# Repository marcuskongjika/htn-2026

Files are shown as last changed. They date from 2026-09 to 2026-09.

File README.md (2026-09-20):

<div align="center">

# ♻️🔋 SortiFy

### Catching hidden batteries *before* they reach the recycling truck.

**SortiFy scans waste for hidden batteries using sensors; it flags and reroutes them before they can cause harm — protecting recycling facilities and waste bins from the hazards posed by lithium batteries.**










</div>

---

## The problem

Vapes, earbuds, toys, greeting cards that sing — more and more of what we throw away has a **lithium-ion battery sealed inside it**. When those cells get crushed in a garbage truck or a sorting line they ignite, and the result is thousands of reported fires at recycling and waste facilities every year.

The catch is that these items **look like ordinary plastic**. A person glancing at a bin can't tell. Neither can a camera. By the time anyone finds out, the item is already in the compactor.

Most solutions work downstream, at the facility. **SortiFy works at the source — the moment you throw something away.**

## What it does

Drop an item on the platform. In a few seconds SortiFy:

1. **notices it** — a load cell feels the weight land,
2. **looks at it** — a camera frame goes to Google's Gemini, which says what the item appears to be made of,
3. **looks *inside* it** — an inductive sensor under the platform checks for metal that no camera could see,
4. **decides** — and the platform physically tilts the item into one of two bins:

| | Bin | What lands here |
|---|---|---|
| 🔋 | **Battery side** | Anything with metal detected in it — routed to e-waste |
| ♻️ | **Non-battery side** | No metal detected — safe for the normal stream |

Then it levels out and is ready for the next item roughly a second later.

### The idea in one sentence

> **A camera sees the outside. An inductive sensor sees the inside. The interesting moment is when they disagree.**

When Gemini says *"that's plastic"* and the sensor says *"there's metal in there"*, you are very probably holding a vape, a toy or a pair of earbuds — and SortiFy says so:

```
sensed: metal_present=True plastic=True -> side=battery
        [looks like plastic but metal detected inside - possible hidden battery]
```

## How it works

```mermaid
flowchart LR
    subgraph sense["Sense"]
        LC["Load cell + HX711<br/><i>item placed?</i>"]
        CAM["Camera"]
        IND["Inductive sensor<br/><i>metal inside?</i>"]
    end
    subgraph think["Decide — Raspberry Pi 5"]
        GEM["Gemini vision<br/><i>looks like plastic?</i>"]
        RULE{"Decision rule"}
        LOG["Explanation<br/>+ logs"]
    end
    subgraph act["Act"]
        SERVO["2 × ST3215 smart servos"]
        BED["Tilting platform"]
    end

    LC -- "weight jumps > 10 g" --> CAM
    CAM --> GEM
    GEM -. "context only" .-> LOG
    IND == "decides the side" ==> RULE
    IND --> LOG
    RULE --> SERVO --> BED
    BED --> B1["🔋 battery bin"]
    BED --> B2["♻️ non-battery bin"]
```

The whole thing is one explicit state machine ([`sorter/main.py`](sorter/main.py)):

```mermaid
stateDiagram-v2
    direction LR
    [*] --> WAITING
    WAITING --> SENSING: weight rises > 10 g
    SENSING --> ACTUATING: metal read + frame classified
    ACTUATING --> HOLDING: platform tilted
    HOLDING --> RESETTING: item has slid off
    RESETTING --> WAITING: level again (~1 s)
    SENSING --> RESETTING: any error → back to level
```

### The decision rule — and why the AI doesn't get the final say

```python
def sort_side(plastic: bool, metal_present: bool) -> str:
    return BATTERY_SIDE if metal_present else NON_BATTERY_SIDE
```

That's the entire rule, and it is short on purpose.

- **The inductive sensor alone decides where an item goes.** Metal detected → battery side. No two ways about it.
- **Gemini never moves an item.** A camera can't see inside anything, so vision is never allowed to put an item on the battery side by itself — and it can never talk an item with metal in it *out* of the battery side. Nothing in the code "assumes" a battery.
- **What Gemini adds is meaning.** Metal + *looks like plastic* is the case this machine exists to catch, and that is the explanation it logs. Metal + *looks like a can* is just a can.
- **If the API is slow, down, or returns junk** (we hit real `503 model overloaded` errors during the hackathon), the classifier returns a result that claims nothing and the item is *still sorted correctly* — the sensor reading was all the rule needed.

A generative model is what made recognising arbitrary household waste possible in a weekend: no dataset, no training, just a prompt and an enforced JSON schema. Keeping it out of the safety-critical path is what makes the machine trustworthy.

## Hardware

| Part | Job | Notes |
|---|---|---|
| **Raspberry Pi 5** (Ubuntu 24.04) | Runs everything | One Python process |
| **Camera** | Frame for Gemini | OpenCV capture |
| **LJ18A3-8-Z/BX inductive sensor** | Metal yes / no | NPN, open collector, active-low on GPIO17 |
| **Bar load cell + HX711** | "An item was placed" | Bit-banged over two GPIOs |
| **2 × Feetech ST3215 smart servos** | Tilt the platform | 12 V, 30 kg·cm, 12-bit absolute encoders, serial bus |
| **3D-printed frame, platform, legs, camera mount** | The machine itself | Designed in Autodesk Inventor — STEP files in this repo |

### Wiring (Raspberry Pi 5 header)

| Pi pin | GPIO | Connects to |
|---|---|---|
| 8 | GPIO14 (TX) | Servo data line, **through a 1 kΩ resistor** |
| 10 | GPIO15 (RX) | Servo data line, directly |
| 11 | GPIO17 | Inductive sensor signal (black wire) |
| 29 | GPIO5 | HX711 `DT` |
| 31 | GPIO6 | HX711 `SCK` |
| 17 | 3.3 V | HX711 `VCC` |
| 6, 9, 25 | GND | Common ground — servos, supply −, both sensors |

The servos run from their own 12 V supply. **Battery/supply positive never touches the Pi.**

## The engineering, honestly

The Devpost says *"physical faults lacked error logs."* Here is what that looked like in the small hours, and what we built because of it.

**We threw away the servo controller board and talked to the servos directly.**
Our USB bus-servo adapter never produced a single reply — not from a laptop, not from the Pi, not with a known-good servo. So we removed it. The ST3215 speaks half-duplex serial at 1 Mbps on one wire; [`sts_bus.py`](sorter/actuators/sts_bus.py) implements that protocol from scratch over the Pi's own UART, with TX and RX tied to the data line through a single resistor. The servos answered on the first try.

**The echo trap.** On a one-wire bus you hear everything you say. Vendor SDKs mistake that echo for the servo's reply — so they cheerfully "find" a servo at every ID, including with nothing plugged in. Our driver reads back and verifies its own echo, which turns a nuisance into a free wiring self-test with three *different* errors instead of one useless timeout:

| Error | What it means |
|---|---|
| `BusWiringError` | We spoke and heard nothing — RX isn't on the wire |
| `BusContentionError` | We heard something we didn't say — a short, or a second driver |
| `ServoTimeout` | Echo perfect, servo silent — it's the servo's power, cable or ID |

**Two servos, one mechanism, facing opposite ways.** [`ServoPair`](sorter/actuators/servo_pair.py) sends both goals in a single sync-write packet so they start in the same instant. Calibration is done by hand, not by maths: torque off, move the platform to level and to each end, and [`read_positions.py`](sorter/tests/read_positions.py) records each servo's own encoder value — detecting by itself which servo is mirrored. No kinematics, no invert flags.

**Three layers between a bug and a broken platform.** Travel limits are written into each servo's EEPROM, so the *servo* refuses to go past them whatever the code asks for. Setpoints sit a further margin inside those limits, so overshoot never reaches them. And torque is capped in config.

**An HX711 that doesn't lie.** That chip treats a clock pulse longer than 60 µs as "power down" — and Python on Linux can be pre-empted mid-pulse. [`hx711.py`](sorter/sensors/hx711.py) drives the pins through `lgpio` directly (~4 µs a pulse), times every pulse, and throws away any reading that was disturbed instead of trusting it. A dead data line is reported as `HX711StuckLow` rather than as a very confident zero grams.

**Weight as a *change*, not a number.** The scan starts when the weight *rises* more than 10 g above a resting level that is re-measured after every dump and follows slow drift. The scale's zero never has to be right — which matters when a load cell gets swapped halfway through a hackathon.

**It all runs without the hardware.** Every device sits behind a mock, and the hardware logic is tested against simulated servos, a simulated HX711 and gpiozero's mock pins — **165 tests**, runnable on a laptop. That is how a team writes code against a single rig.

## Run it

```bash
git clone https://github.com/marcuskongjika/htn-2026.git
cd htn-2026/sorter
python3 -m venv .venv && source .venv/bin/activate
pip install -r requirements.txt
cp .env.example .env          # add GEMINI_API_KEY; MOCK_HARDWARE=1 on a laptop, 0 on the Pi
```

| Command | What it does |
|---|---|
| `python main.py` | The full sorter. A weight landing on the platform starts each scan |
| `python main_enter.py` | Same pipeline, but **Enter** starts each scan — no load cell needed |
| `python -m pytest tests -q` | 165 tests, no hardware required |
| `MOCK_HARDWARE=1 python main.py --cycles 1` | One full cycle on a laptop, nothing attached |

### Bring-up and diagnostic tools

Every one of these exists because something broke. The ones that move hardware ask first.

| Tool | Use it when |
|---|---|
| `python -m actuators.sts_bus scan` | "Are the servos alive?" — IDs, position, voltage, temperature, limits |
| `python -m actuators.sts_bus loopback` | Prove the UART and the TX/RX tie before a servo is even connected |
| `python tests/read_positions.py` | Calibrate: move the platform by hand, record level / min / max, save |
| `python -m actuators.calibration apply` | Write the travel limits into the servos' EEPROM |
| `python tests/goto_setpoints.py` | Drive the platform to level / battery / non_battery and nothing else |
| `python tests/sensor_tilt_loop.py` | Metal sensor → platform, without the camera or the API |
| `python tests/load_cell_read.py` | Live scale readout; tare, calibrate against a known weight, save |
| `python tests/gpio_check.py` | "Is it the Pi pin, the jumper wire, or the board?" — answers exactly that |

Full setup, wiring and bring-up order: **[`sorter/README.md`](sorter/README.md)**.

## Repository

```
htn-2026/
├── sortify_*.stp                 CAD — platform, base, legs, floor, camera mount (STEP)
└── sorter/
    ├── main.py                   state machine, load-cell triggered
    ├── main_enter.py             same pipeline, Enter triggered
    ├── config.py                 every pin, threshold, margin and timing in one place
    ├── logic/decision.py         the sorting rule (it's one line)
    ├── vision/                   camera capture + Gemini classifier
    ├── sensors/                  hx711 driver, load cell, inductive metal sensor
    ├── actuators/
    │   ├── sts_bus.py            ST3215 protocol over the Pi's UART, from scratch
    │   ├── servo_pair.py         two servos as one mechanism
    │   └── calibration.py        measured zero / travel / mirroring, shared everywhere
    ├── tests/                    165 tests + the physical bring-up tools
    └── *_calibration.json        what we measured on the rig
```

## What we learned

- **Details decide whether a system works.** A pin one position over, a resistor on the wrong leg, a jumper that *looks* seated.
- **Test components early and alone.** Every part that was proven by itself before integration cost us minutes. Every part that wasn't cost us hours.
- **Hardware and software fail differently.** Software tells you what went wrong. Hardware just stops — so we made the software say *which side of the wire* to look at.
- **Calibrate against real objects, not assumptions.** The servos' limits, the scale's counts-per-gram, the sensor's range: every number in this repo that matters was measured on the rig.

## What's next

- **More categories** — plastics, metals, glass, paper, each to its own stream
- **Broader sensing** — more item types, more robust detection of pouch cells
- **Bigger installations** — campuses, airports, offices
- **Contamination insights** — give facilities data on what is actually being thrown away, and where

## Team

Built over one weekend at **Hack the North 2026** by

**[Sharisse Ji](https://www.linkedin.com/in/sharisseji/)** · **[Zhi Wei Zhang](https://www.linkedin.com/in/zhiweizhang27)** · **[Andrii Bessarab](https://www.linkedin.com/in/andriibessarab/)** · **[Marcus Kongjika](https://www.linkedin.com/in/marcus-kongjika-b5476b2b8/)**

<div align="center">

**[▶ See SortiFy on Devpost](https://devpost.com/software/sortify-fbow2t)**

*Built with Python, Google Gemini and Autodesk Inventor.*

</div>

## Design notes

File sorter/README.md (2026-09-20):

# Battery Sorter

Raspberry Pi 5 pipeline that flags waste items likely to contain a hidden
battery. A load cell (HX711) and an inductive metal sensor cross-check a

Gemini photo classification of the item (whether it is plastic, and whether it
likely contains a hidden battery), then drive two STS3215 smart servos to tilt
the item to the **battery side** or the **non-battery side**. The induction sensor
alone decides: metal detected -> battery side, no metal -> non-battery side. The
camera explains the result (plastic + metal = a possible hidden battery); it never
moves an item.

The pipeline is an explicit state machine (`main.py`) gated by the load cell —
nothing is captured until an item's weight is sensed:

```
WAITING -> (weight >= WEIGHT_TRIGGER_G) -> SENSING -> ACTUATING -> HOLDING -> RESETTING -> WAITING
   '-------------------- (below trigger: keep polling) --------------------'
```

WAITING polls the load cell. When an item's weight crosses `WEIGHT_TRIGGER_G`,
SENSING lets it settle, reads the metal sensor, and classifies the camera frame;
the bed then tilts (metal detected -> battery side; no metal -> non-battery side), holds
for `TILT_HOLD_S` (default 5 s), returns to level, and waits for the next item.
On real hardware the load cell tares at start-up and after each dump.

Every hardware-touching module (`sensors/`, `vision/camera.py`,
`actuators/`) has a **mock mode** that returns synthetic data instead of
touching real GPIO/serial/camera. This is not a fallback bolted on — it's
how the whole pipeline is meant to be developed and demoed before hardware
is available.

## Install

```bash
cd sorter
python3 -m venv .venv
source .venv/bin/activate
pip install -r requirements.txt
```

`RPi.GPIO` only installs on ARM (the Pi itself); on a laptop, `pip install`
will skip it via the platform marker in `requirements.txt`, and mock mode
never imports it anyway.

## Configure

```bash
cp .env.example .env
```

Edit `.env` and set:

```
GEMINI_API_KEY=your-real-key-here
MOCK_HARDWARE=1   # 1 on a laptop with no hardware, 0 on the Pi with hardware attached
```

`.env` is gitignored — never commit real keys.

## Run in mock mode (no hardware attached)

With `MOCK_HARDWARE=1` (the default), the whole pipeline — including a
canned Gemini-shaped response, no network call — runs end to end on a
laptop. The mock load cell's baseline weight sits above `WEIGHT_TRIGGER_G`, so
it fires every loop; it runs until Ctrl+C:

```bash
python main.py                                # runs until Ctrl+C
TILT_HOLD_S=1 python main.py --cycles 2       # bounded demo: 2 cycles, short hold
```

`--cycles N` stops after N completed cycles; `TILT_HOLD_S` tunes the hold at the
tilt. Every state transition and sensor/decision value is logged to stdout and
to `logs/sorter.log` (rotating, see `config.LOG_MAX_BYTES` /
`config.LOG_BACKUP_COUNT`).

To test just the material classifier against the real Gemini API while
everything else stays mocked, set `MOCK_HARDWARE=0` but note that will also
try to open the camera/GPIO/serial — see the bring-up order below for how
to exercise modules individually instead.

Run the decision-logic unit tests any time (pure function, no mocking
needed):

```bash
python -m pytest tests/test_decision.py -v
```

## Testing

All of these run without hardware. Activate the venv first (`source .venv/bin/activate`).

**Mock Gemini + decision unit tests** (offline, no API key, no camera):

```bash
python -m pytest tests/test_classifier.py tests/test_decision.py -v
```

`test_classifier.py` mocks Gemini two ways: the built-in canned-response path,
and a *fake `google.genai` SDK* injected into `sys.modules` so the real
request-build / JSON-parse code in `classify_material` runs offline. It also
covers fail-toward-"flagged" behavior on malformed output, errors, and timeouts.

**Webcam smoke test** (real camera capture + *mocked* Gemini) — captures one
frame from this machine's webcam, verifies the JPEG, then classifies it in mock
mode so no API quota is spent:

```bash
python -m tests.webcam_smoke              # camera index 0 (default webcam)
python -m tests.webcam_smoke --index 1    # a different camera
python -m tests.webcam_smoke --real-gemini  # real camera + REAL Gemini (needs GEMINI_API_KEY)
```

> **WSL2 note:** OpenCV inside WSL2 cannot see the Windows webcam — there is no
> `/dev/video*` unless you attach the USB device with `usbipd-win` and run a
> UVC-capable WSL kernel. The simplest path on Windows+WSL is to run the webcam
> test under **Windows Python** instead:
>
> ```powershell
> cd <repo>\sorter
> python -m venv .venv-win
> .venv-win\Scripts\activate
> pip install opencv-python python-dotenv google-genai
> python -m tests.webcam_smoke --real-gemini
> ```

**Seeing how Gemini categorizes an item** — `--real-gemini` above prints the raw
JSON verdict (`plastic`, `plastic_confidence`, `likely_contains_battery`,
`confidence`). `plastic` is `true` when `plastic_confidence` exceeds 0.5
(`config.PLASTIC_CONFIDENCE_THRESHOLD`). You can also
run the classifier standalone against the real API (`MOCK_HARDWARE=0`, key set):

```bash
python -m vision.classifier   # captures a frame and prints the classification
```

Both `vision/classifier.py` and `main.py` also log `Gemini classification: {...}`
/ `classified: {...}` at INFO to stdout and `logs/sorter.log`.

## Hardware bring-up order (on the real Pi)

Bring the system up incrementally, in this order, rather than plugging
everything in and running `main.py` cold:

1. **Verify power rails before connecting the Pi.** Confirm 3.3V and GND on
   the load cell and metal sensor headers with a multimeter before
   attaching anything to the Pi's GPIO pins.
2. **Bring up the Pi standalone — camera capture + one real Gemini call.**
   With `MOCK_HARDWARE=0` and a real `GEMINI_API_KEY` set:
   ```bash
   python -m vision.camera      # writes capture_test.jpg
   python -m vision.classifier  # captures a frame and classifies it
   ```
3. **`python -m sensors.load_cell` alone, calibrate zero/scale.** Run it
   standalone, tare with nothing on the scale, then place a known reference
   weight and adjust `HX711_REFERENCE_UNIT` / `HX711_ZERO_OFFSET` in
   `config.py` until `read_weight_g()` matches reality.
4. **`python -m sensors.metal_sensor` alone, confirm it toggles near
   metal.** Wave a metal object near the sensor face and confirm
   `metal_present` flips (LOW = detected, per the sensor's active-low
   wiring).
5. **Bring up the servo bus — see "Servo bring-up" below.** Loopback first
   (no servo attached), then scan, then a single move with the horn free,
   and only then `python -m actuators.servo_controller`.
6. **Run `logic/decision.py`'s `sort_side()` against printed sensor/vision
   output with servos disconnected.** Feed real metal + plastic readings from
   steps 2-4 into `sort_side(plastic, metal_present)` by hand (or via
   `python -m tests.test_decision`) and sanity-check which bin each combination
   picks before anything can physically move.
7. **Run `main.py` fully on the shared battery rail with a real test
   item.** Only after 1-6 pass, set `MOCK_HARDWARE=0` and run
   `python main.py` with power to the full system and a real item.

## Servo bring-up (direct UART, no adapter board)

The STS3215 talks half-duplex serial at 1 Mbps on a single data wire.
`actuators/sts_bus.py` speaks that protocol over the Pi's own UART and does
the job the USB adapter board used to do (framing, discarding its own echo,
parsing replies). No vendor SDK is involved.

### One-time Pi setup

On a Pi 5 the header UART (GPIO14/15) is off by default. Add to
`/boot/firmware/config.txt` and reboot:

```
dtparam=uart0=on
```

It appears as `/dev/ttyAMA0` (the default `SERVO_PORT`). Check with
`pinctrl get 14,15` - the pins should show `TXD0` / `RXD0`. If
`/boot/firmware/cmdline.txt` contains `console=ttyAMA0` or a
`serial-getty@ttyAMA0` service is running, remove/disable it so nothing else
writes to the servo bus. The user must be in the `dialout` group.

### Wiring

```
Pi GPIO14 (TX, pin 8)  --[ 1 kOhm ]--+
Pi GPIO15 (RX, pin 10) --------------+---- servo DATA
Pi GND (pin 6) --------------------------- servo GND  and  battery -
battery + -------------------------------- servo V+        (NEVER to the Pi)
```

The resistor is what makes one wire work both ways: the Pi drives the line
through it, and the servo can still pull the line when it replies. TX idling
high through the resistor is also the line's pull-up.

**Before connecting RX:** power the servo on its own and measure DATA to GND
with a multimeter. It must be 3.6 V or less. If it is near 5 V, put a voltage
divider or level shifter in front of GPIO15 - the Pi's pins are 3.3 V.

### Bring-up order

```bash
python -m actuators.sts_bus loopback      # 1. NO servo attached. Proves the UART runs at 1 Mbps and RX sees TX
python -m actuators.sts_bus scan --all    # 2. servo attached + powered: lists every ID that answers
python -m actuators.sts_bus watch 1       # 3. torque off; turn the horn by hand and read the ticks (pose recording)
python -m tools.nudge 1                   # 4. first motion: +100 ticks slowly at 30% torque, then back. Asks before moving;
                                          #    refuses if the servo's stored angle limits would turn it into a big swing
python -m actuators.sts_bus move 1 2048   #    then a full move to centre, horn free
python -m actuators.servo_controller      # 5. home -> safe -> flagged -> home (MOCK_HARDWARE=0)
```

The bus reports *which side* is broken instead of a generic timeout:

| Error | Meaning | Look at |
|---|---|---|
| `BusWiringError` | We sent bytes and heard nothing, not even our own echo | TX/RX tie, UART enabled, right `/dev/tty*` |
| `BusContentionError` | What we heard while sending wasn't what we sent | Short, second device on the line, bad ground |
| `ServoTimeout` | Echo was perfect, the servo said nothing | Servo power, the 3-pin cable, servo ID, baud rate |

Servo IDs come from `.env` (`SERVO_ID_SAFE_GATE`, `SERVO_ID_FLAGGED_GATE`).
Setting both to the same ID is the single-servo build: one servo tilts either
way from home. A USB bus adapter still works - set `SERVO_PORT=/dev/ttyACM0`;
the echo is auto-detected either way.

## Sorting rule

`logic/decision.py`, `sort_side(plastic, metal_present)`. **The induction sensor is the only
thing that decides the side:**

- **metal detected -> the battery side.** No two ways about it: whatever the camera thinks,
  an item with metal in it never goes to the non-battery side.
- **no metal -> the non-battery side.** That includes things that aren't plastic (paper,
  glass, food): "not plastic" is not evidence of a battery, and nothing is assumed.

Gemini's answer (`plastic`, and its `likely_contains_battery` guess) is **logged, never acted
on** - a camera can't see inside anything. What it adds is the explanation, from
`describe()`: *plastic + metal* is the case this machine exists to catch, "looks like plastic
but metal detected inside - possible hidden battery". If the Gemini call fails or times out,
the classifier returns a result that claims nothing (`plastic: False,
likely_contains_battery: False`) and the item is still sorted correctly, because the sensor
reading is all that was needed.

The code only ever says `battery` / `non_battery`. Which physical end of the bed each one is
lives in one place: `BATTERY_SIDE_SETPOINT` in `config.py` (or `.env`) - `max` by default,
so `non_battery` is `min`. Swap the bins on the table, change that one value. The bed rests
at `go_level()` between items. In `main.py` the load cell gates the pipeline (an item is only
scanned once its weight is sensed); `main_enter.py` is the same pipeline started by pressing
Enter, with no load cell involved.

## Directory structure

```
sorter/
├── config.py                    # pins, calibration constants, thresholds, .env loading
├── sensors/
│   ├── load_cell.py              # HX711 wrapper
│   └── metal_sensor.py           # inductive sensor wrapper
├── vision/
│   ├── camera.py                 # OpenCV frame capture
│   └── classifier.py             # Gemini plastic + battery classification
├── actuators/
│   ├── sts_bus.py                # STS servo protocol over the Pi UART (half-duplex) + bring-up CLI
│   ├── servo_pair.py             # leader/follower bed pair: go_level / go_min / go_max (used by main.py)
│   └── servo_controller.py       # legacy home / move_safe / move_flagged demo (not used by main.py)
├── logic/
│   └── decision.py               # pure sort_side(plastic, metal) rule
├── tests/
│   ├── test_decision.py          # unit tests for the sorting rule
│   ├── test_sts_bus.py           # servo bus tests against a fake wire + fake servo
│   └── test_nudge.py             # nudge tool against a simulated moving servo
├── tools/
│   └── nudge.py                  # first-motion test: small, slow, gentle move and back
├── main.py                       # the state machine loop
├── .env.example
├── requirements.txt
└── README.md
```

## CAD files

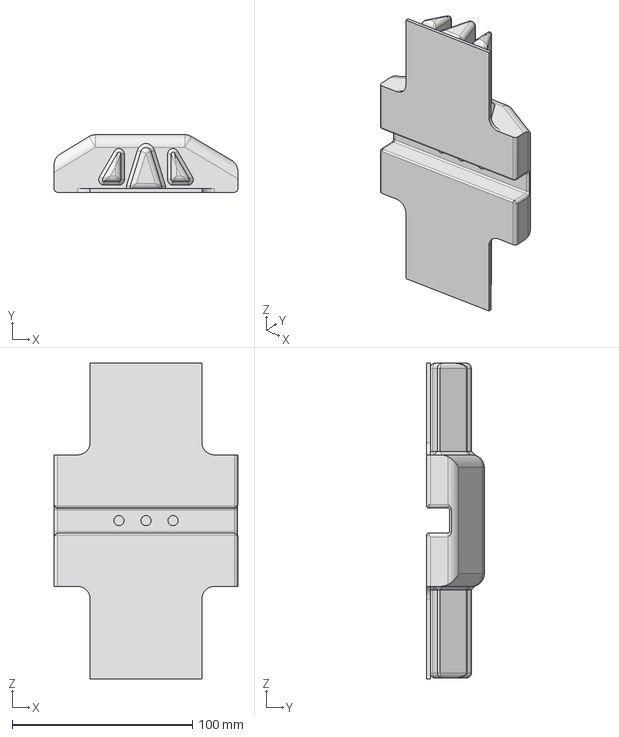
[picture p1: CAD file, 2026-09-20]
sortify_base_cantilever.stp
102.0 x 32.0 x 175.4 mm

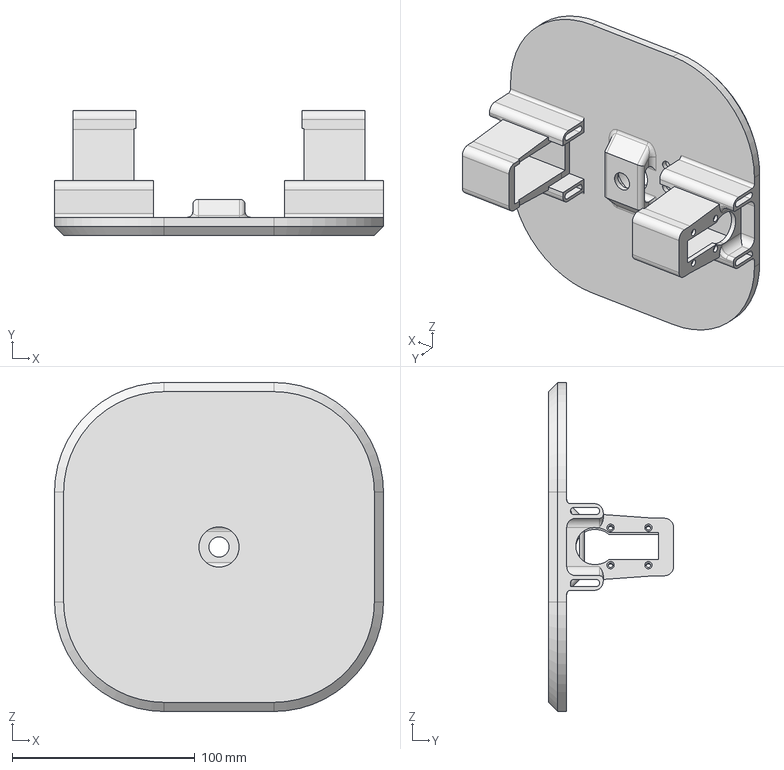
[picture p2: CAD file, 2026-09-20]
sortify_platform.stp
180.0 x 68.5 x 180.0 mm

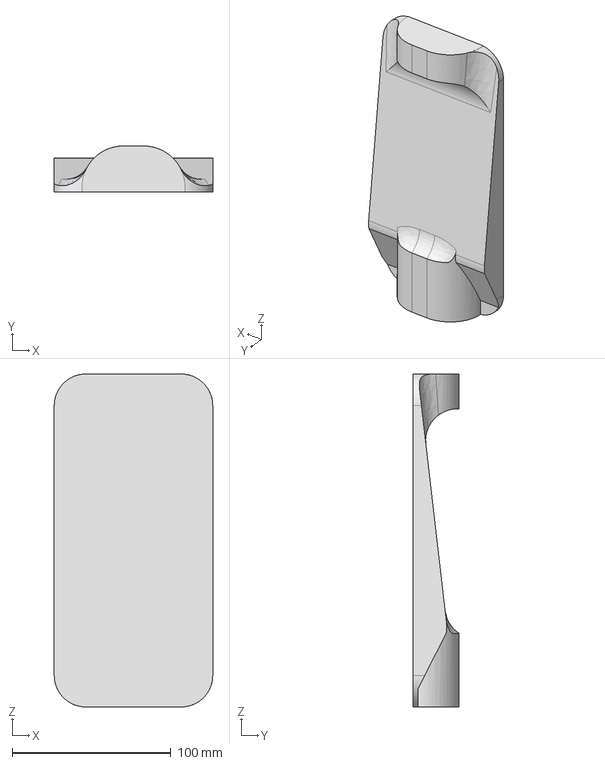
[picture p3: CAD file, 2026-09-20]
sortify_floor.stp
100.0 x 29.0 x 210.0 mm

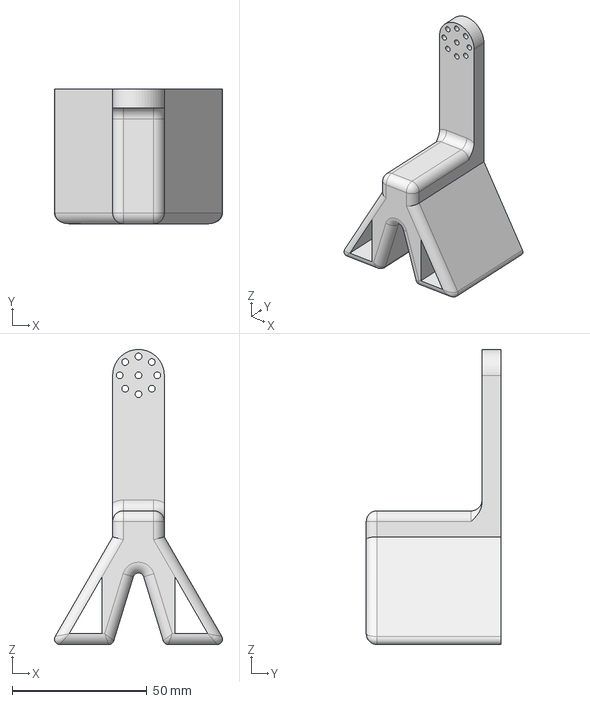
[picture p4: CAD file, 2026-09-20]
sortify_leg.stp
62.5 x 50.0 x 109.6 mm

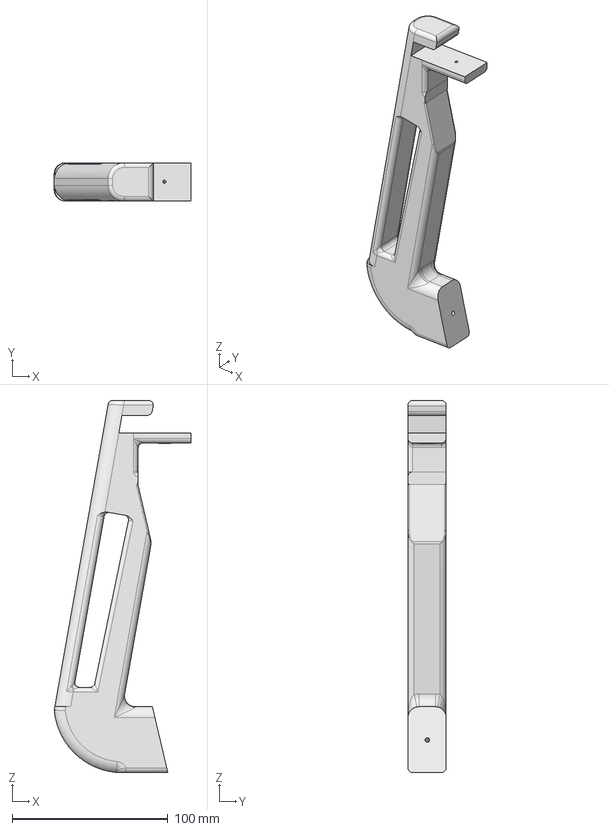
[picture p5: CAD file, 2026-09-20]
sortify_camera_mount.stp
87.7 x 24.6 x 238.8 mm

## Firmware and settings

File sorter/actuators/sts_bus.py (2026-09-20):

"""Feetech STS/ST-series servo bus, spoken directly over a serial port.

This replaces the USB bus servo adapter board *and* the vendor SDK. The Pi's
own UART (GPIO14 TX / GPIO15 RX, `/dev/ttyAMA0` on a Pi 5) is wired straight
to the servo's one-wire data line:

    Pi GPIO14 (TX, pin 8)  --[ 1k ]--+
    Pi GPIO15 (RX, pin 10) ----------+---- servo DATA
    Pi GND ------------------------------- servo GND + battery -
    battery + ---------------------------- servo V+   (never to the Pi)

Because TX and RX share that one wire, every byte we send arrives back on RX
before the servo's reply does. This module is the "translation" the adapter
board used to do: it frames packets, swallows its own echo, and parses the
reply. The echo is also a free wiring self-test, which is why there are three
distinct failures instead of one generic timeout:

    BusWiringError      we sent bytes and heard nothing  -> RX isn't on the wire
    BusContentionError  we heard something else          -> the line is being fought over
    ServoTimeout        echo was perfect, servo was silent -> servo side (power, cable, ID, baud)

Packet format, both directions (low byte first for 16-bit values):

    FF FF | ID | LEN | INSTRUCTION or ERROR | PARAMS... | CHECKSUM
    LEN = len(PARAMS) + 2          CHECKSUM = ~(ID + LEN + INSTR + PARAMS) & 0xFF

Bring-up CLI (run from sorter/):

    python -m actuators.sts_bus loopback        # no servo needed: proves UART + TX/RX tie at full baud
    python -m actuators.sts_bus scan [--all]    # who is on the bus, and what do they report
    python -m actuators.sts_bus watch <id>      # torque off, live position - for recording poses
    python -m actuators.sts_bus move <id> <pos> # one move at config speed/acc
"""
from __future__ import annotations

import logging
import os
import sys
import time

log = logging.getLogger(__name__)

# --- Protocol constants ------------------------------------------------------
HEADER = b"\xff\xff"
BROADCAST_ID = 0xFE

INST_PING = 0x01
INST_READ = 0x02
INST_WRITE = 0x03
INST_SYNC_WRITE = 0x83

# Register addresses (STS3215 control table)
ADDR_ID = 5
ADDR_MIN_ANGLE_LIMIT = 9      # 2 bytes, EEPROM
ADDR_MAX_ANGLE_LIMIT = 11     # 2 bytes, EEPROM
ADDR_MODE = 33                # 0 = position servo
ADDR_TORQUE_ENABLE = 40
ADDR_ACC = 41                 # start of the 7-byte block write_pos_ex writes
ADDR_GOAL_POSITION = 42
ADDR_GOAL_SPEED = 46          # 2 bytes; in wheel mode this IS the command (bit 15 = reverse)
ADDR_TORQUE_LIMIT = 48        # 2 bytes, 0-1000
ADDR_LOCK = 55                # 0 = EEPROM writable, 1 = locked
ADDR_PRESENT_POSITION = 56    # start of the 15-byte feedback block

MODE_POSITION = 0             # go to an angle and hold it
MODE_WHEEL = 1                # spin continuously at a speed, like a motor

FEEDBACK_LEN = 15
POSITION_MAX = 4095
TICKS_PER_REV = 4096

# Status-packet error bits
ERROR_BITS = {0: "voltage", 1: "sensor", 2: "temperature", 3: "current", 5: "overload"}


class StsBusError(RuntimeError):
    """Base class for everything this module raises."""


class BusWiringError(StsBusError):
    """We transmitted and heard nothing back, not even our own echo."""


class BusContentionError(StsBusError):
    """What came back while we were transmitting wasn't what we sent."""


class ServoTimeout(StsBusError):
    """The bus is fine (echo intact) but the servo didn't answer."""

    def __init__(self, servo_id: int) -> None:
        super().__init__(f"servo {servo_id} did not reply (bus echo was fine - check servo power, cable, ID, baud)")
        self.servo_id = servo_id


class BadReply(StsBusError):
    """A reply arrived but failed validation (checksum, ID, or length)."""


def build_packet(servo_id: int, instruction: int, params: bytes = b"") -> bytes:
    body = bytes([servo_id, len(params) + 2, instruction]) + bytes(params)
    return HEADER + body + bytes([~sum(body) & 0xFF])


def _signed(value: int, sign_bit: int) -> int:
    """STS servos use sign-magnitude: one bit is the minus sign, the rest is the number."""
    magnitude = value & ((1 << sign_bit) - 1)
    return -magnitude if value & (1 << sign_bit) else magnitude


class StsBus:
    def __init__(
        self,
        port: str,
        baudrate: int = 1_000_000,
        reply_timeout_s: float = 0.05,
        echo: bool | None = None,
        serial_port=None,
    ) -> None:
        """Open the bus.

        echo: True = TX and RX share the wire (direct UART wiring); False = an
        adapter that hides the echo; None = find out by probing once.
        serial_port: an already-open pyserial-like object (used by the tests).
        """
        self.port = port
        self.reply_timeout_s = reply_timeout_s
        if serial_port is not None:
            self._ser = serial_port
        else:
            import serial  # imported here so mock mode / tests never need pyserial

            self._ser = serial.Serial(port, baudrate, timeout=0.005)
        self.echo = self._detect_echo() if echo is None else echo
        log.info("StsBus open on %s @ %d baud (echo=%s)", port, baudrate, self.echo)

    # --- low level -----------------------------------------------------------
    def _read_exact(self, count: int, timeout_s: float) -> bytes:
        got = bytearray()
        deadline = time.monotonic() + timeout_s
        while len(got) < count and time.monotonic() < deadline:
            got += self._ser.read(count - len(got))
        return bytes(got)

    def _detect_echo(self) -> bool:
        probe = build_packet(BROADCAST_ID, INST_PING)  # harmless: moves nothing
        self._ser.reset_input_buffer()
        self._ser.write(probe)
        self._ser.flush()
        heard = self._read_exact(len(probe), 0.05)
        time.sleep(0.01)  # let any servo's answer to the probe arrive, then drop it
        self._ser.reset_input_buffer()
        return heard == probe

    def _send(self, packet: bytes) -> None:
        self._ser.reset_input_buffer()
        self._ser.write(packet)
        self._ser.flush()
        if not self.echo:
            return
        heard = self._read_exact(len(packet), 0.05)
        if not heard:
            raise BusWiringError(
                f"sent {len(packet)} bytes on {self.port} and heard nothing - RX is not seeing TX "
                "(check the TX/RX tie, and that the UART is enabled)"
            )
        if heard != packet:
            raise BusContentionError(
                f"sent {packet.hex(' ')} but heard {heard.hex(' ')} - something else is driving the data line"
            )

    def _read_reply(self, servo_id: int, timeout_s: float) -> tuple[int, bytes]:
        """Returns (error_byte, params). Raises ServoTimeout / BadReply."""
        head = self._read_exact(4, timeout_s)  # FF FF ID LEN
        if len(head) < 4:
            raise ServoTimeout(servo_id)
        if head[:2] != HEADER:
            raise BadReply(f"servo {servo_id}: reply did not start with FF FF: {head.hex(' ')}")
        reply_id, length = head[2], head[3]
        rest = self._read_exact(length, timeout_s)  # ERROR PARAMS... CHECKSUM
        if len(rest) < length:
            raise BadReply(f"servo {servo_id}: reply cut short: {(head + rest).hex(' ')}")
        if ~(reply_id + length + sum(rest[:-1])) & 0xFF != rest[-1]:
            raise BadReply(f"servo {servo_id}: bad checksum: {(head + rest).hex(' ')}")
        if reply_id != servo_id:
            raise BadReply(f"asked servo {servo_id} but servo {reply_id} answered")
        return rest[0], rest[1:-1]

    def _transact(self, servo_id: int, instruction: int, params: bytes = b"", timeout_s: float | None = None):
        self._send(build_packet(servo_id, instruction, params))
        if servo_id == BROADCAST_ID:
            return 0, b""  # nobody answers a broadcast write
        return self._read_reply(servo_id, self.reply_timeout_s if timeout_s is None else timeout_s)

    # --- public API ------------------------------------------------------------
    def ping(self, servo_id: int, timeout_s: float | None = None) -> bool:
        """True if the servo answered. Wiring/contention problems still raise."""
        try:
            self._transact(servo_id, INST_PING, timeout_s=timeout_s)
            return True
        except (ServoTimeout, BadReply):
            return False

    def scan(self, ids=range(0, 31)) -> list[int]:
        return [sid for sid in ids if self.ping(sid, timeout_s=0.01)]

    def read(self, servo_id: int, address: int, length: int) -> bytes:
        _error, params = self._transact(servo_id, INST_READ, bytes([address, length]))
        if len(params) != length:
            raise BadReply(f"servo {servo_id}: asked for {length} bytes at {address}, got {len(params)}")
        return params

    def read_byte(self, servo_id: int, address: int) -> int:
        return self.read(servo_id, address, 1)[0]

    def read_word(self, servo_id: int, address: int) -> int:
        data = self.read(servo_id, address, 2)
        return data[0] | (data[1] << 8)

    def write(self, servo_id: int, address: int, data: bytes) -> int:
        """Write registers. Returns the servo's error byte (0 = healthy)."""
        error, _params = self._transact(servo_id, INST_WRITE, bytes([address]) + bytes(data))
        return error

    def write_byte(self, servo_id: int, address: int, value: int) -> int:
        return self.write(servo_id, address, bytes([value & 0xFF]))

    def write_word(self, servo_id: int, address: int, value: int) -> int:
        return self.write(servo_id, address, bytes([value & 0xFF, (value >> 8) & 0xFF]))

    def set_torque(self, servo_id: int, enabled: bool) -> int:
        return self.write_byte(servo_id, ADDR_TORQUE_ENABLE, 1 if enabled else 0)

    def angle_limits(self, servo_id: int) -> tuple[int, int]:
        """(min, max) goal position the servo will accept. It clamps anything outside."""
        return self.read_word(servo_id, ADDR_MIN_ANGLE_LIMIT), self.read_word(servo_id, ADDR_MAX_ANGLE_LIMIT)

    def set_angle_limits(self, servo_id: int, lower: int, upper: int) -> None:
        """Write the limits to EEPROM (unlock, write, lock). EEPROM has a finite
        write life, so this skips the write when the stored values already match."""
        if self.angle_limits(servo_id) == (lower, upper):
            return
        self.write_byte(servo_id, ADDR_LOCK, 0)
        try:
            self.write_word(servo_id, ADDR_MIN_ANGLE_LIMIT, lower)
            self.write_word(servo_id, ADDR_MAX_ANGLE_LIMIT, upper)
        finally:
            self.write_byte(servo_id, ADDR_LOCK, 1)

    @staticmethod
    def _pos_ex_block(position: int, speed: int, acc: int) -> bytes:
        """The 7 bytes at ADDR_ACC: acc, position lo/hi, time 0/0, speed lo/hi."""
        position = max(0, min(POSITION_MAX, int(position)))
        return bytes([acc & 0xFF, position & 0xFF, position >> 8, 0, 0, speed & 0xFF, (speed >> 8) & 0xFF])

    def write_pos_ex(self, servo_id: int, position: int, speed: int, acc: int = 0) -> int:
        """Go to position (0-4095). speed in steps/s (0 = no cap), acc in 100 steps/s^2 (0 = no ramp)."""
        return self.write(servo_id, ADDR_ACC, self._pos_ex_block(position, speed, acc))

    def sync_write_pos_ex(self, moves: list[tuple[int, int, int, int]]) -> None:
        """Start several servos in one packet. moves = [(id, position, speed, acc), ...]. No replies."""
        params = bytearray([ADDR_ACC, 7])
        for servo_id, position, speed, acc in moves:
            params.append(servo_id)
            params += self._pos_ex_block(position, speed, acc)
        self._transact(BROADCAST_ID, INST_SYNC_WRITE, bytes(params))

    @staticmethod
    def _encode_speed(speed: int) -> bytes:
        """Signed speed as the servo wants it: sign-magnitude, bit 15 = reverse, low byte first."""
        encoded = min(abs(int(speed)), 0x7FFF) | (0x8000 if speed < 0 else 0)
        return bytes([encoded & 0xFF, encoded >> 8])

    # Wheel-mode commands write ONLY the acceleration and goal-speed registers. They never
    # touch the goal position (42-43): a speed command that reaches a servo which is in
    # position mode must not be able to send it anywhere.
    def write_speed(self, servo_id: int, speed: int, acc: int = 0) -> int:
        """Wheel mode: spin at speed steps/s (negative = reverse, 0 = stop)."""
        self.write_byte(servo_id, ADDR_ACC, acc)
        return self.write(servo_id, ADDR_GOAL_SPEED, self._encode_speed(speed))

    def sync_write_speed(self, spins: list[tuple[int, int, int]]) -> None:
        """Wheel mode, several servos: ramps set one by one, then every speed in ONE
        packet so they all start (or stop) together. spins = [(id, speed, acc), ...]."""
        for servo_id, _speed, acc in spins:
            self.write_byte(servo_id, ADDR_ACC, acc)
        params = bytearray([ADDR_GOAL_SPEED, 2])
        for servo_id, speed, _acc in spins:
            params.append(servo_id)
            params += self._encode_speed(speed)
        self._transact(BROADCAST_ID, INST_SYNC_WRITE, bytes(params))

    def feedback(self, servo_id: int) -> dict:
        """Everything the servo reports about itself, in one read."""
        d = self.read(servo_id, ADDR_PRESENT_POSITION, FEEDBACK_LEN)
        status = d[9]
        return {
            "position": _signed(d[0] | (d[1] << 8), 15),          # ticks
            "speed": _signed(d[2] | (d[3] << 8), 15),             # steps/s
            "load": _signed(d[4] | (d[5] << 8), 10) / 10.0,       # % of max, sign = direction
            "voltage": d[6] / 10.0,                               # V
            "temperature": d[7],                                  # C
            "moving": bool(d[10]),
            "current_ma": _signed(d[13] | (d[14] << 8), 15) * 6.5,
            "errors": [name for bit, name in ERROR_BITS.items() if status & (1 << bit)],
        }

    def close(self) -> None:
        self._ser.close()


# --- bring-up CLI ----------------------------------------------------------------
def _loopback(port: str, baudrate: int) -> int:
    import serial

    # No 0xFF bytes: a servo that happens to be attached can never see a packet header.
    blob = bytes(b % 0xFF for b in os.urandom(200))
    with serial.Serial(port, baudrate, timeout=0.5) as ser:
        ser.reset_input_buffer()
        ser.write(blob)
        ser.flush()
        heard = ser.read(len(blob))
    print(f"{port} @ {baudrate}: sent {len(blob)} bytes, heard {len(heard)}, identical={heard == blob}")
    if heard == blob:
        print("OK - the UART works at this baud and RX sees TX. Safe to connect the servo.")
        return 0
    if not heard:
        print("Heard nothing: RX isn't connected to the data wire, or this isn't the header UART.")
    else:
        print("Heard different bytes: bad connection, or something else is driving the line.")
    return 1


def _cli(argv: list[str]) -> int:
    import argparse

    import config

    ap = argparse.ArgumentParser(prog="python -m actuators.sts_bus", description=__doc__,
                                 formatter_class=argparse.RawDescriptionHelpFormatter)
    ap.add_argument("--port", default=config.SERVO_PORT)
    ap.add_argument("--baud", type=int, default=config.SERVO_BAUDRATE)
    sub = ap.add_subparsers(dest="cmd", required=True)
    sub.add_parser("loopback")
    p = sub.add_parser("scan")
    p.add_argument("--all", action="store_true", help="IDs 0-253 instead of 0-50")
    p = sub.add_parser("watch")
    p.add_argument("id", type=int)
    p = sub.add_parser("move")
    p.add_argument("id", type=int)
    p.add_argument("position", type=int)
    args = ap.parse_args(argv)

    try:
        if args.cmd == "loopback":
            return _loopback(args.port, args.baud)
        bus = StsBus(args.port, args.baud)
    except OSError as e:  # pyserial's SerialException is an OSError
        print(f"Could not open {args.port}: {e}")
        return 1
    try:
        print(f"{args.port} @ {args.baud}, echo={'yes' if bus.echo else 'no'}")
        if args.cmd == "scan":
            ids = range(0, 254) if args.all else range(0, 51)
            found = bus.scan(ids)
            if not found:
                print(f"No servo answered on IDs {ids[0]}-{ids[-1]}.")
                return 1
            for sid in found:
                fb = bus.feedback(sid)
                print(f"ID {sid}: pos {fb['position']} ({fb['position'] * 360 / TICKS_PER_REV:.1f} deg), "
                      f"{fb['voltage']:.1f} V, {fb['temperature']} C, mode {bus.read_byte(sid, ADDR_MODE)}, "
                      f"limits [{bus.read_word(sid, ADDR_MIN_ANGLE_LIMIT)}, {bus.read_word(sid, ADDR_MAX_ANGLE_LIMIT)}], "
                      f"errors {fb['errors'] or 'none'}")
        elif args.cmd == "watch":
            bus.set_torque(args.id, False)
            print(f"Servo {args.id}: torque off, move it by hand. Ctrl+C to exit.")
            try:
                while True:
                    pos = bus.feedback(args.id)["position"]
                    print(f"\rpos {pos:5d} ticks  ({pos * 360 / TICKS_PER_REV:6.1f} deg)   ", end="", flush=True)
                    time.sleep(0.1)
            except KeyboardInterrupt:
                print()
        elif args.cmd == "move":
            bus.set_torque(args.id, True)
            error = bus.write_pos_ex(args.id, args.position, config.SERVO_MOVE_SPEED, config.SERVO_MOVE_ACC)
            print(f"servo {args.id} -> {args.position} (error byte {error})")
        return 0
    except StsBusError as e:
        print(f"{type(e).__name__}: {e}")
        return 1
    finally:
        bus.close()


if __name__ == "__main__":
    sys.exit(_cli(sys.argv[1:]))

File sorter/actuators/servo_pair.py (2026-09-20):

"""Two servos driven as one: a leader and a follower on the same bus.

    from actuators.servo_pair import ServoPair

    with ServoPair((43, 13), invert=(False, True)) as pair:
        pair.move_by(300)            # POSITION mode: both go +300 ticks (13 mirrored), wait, hold
        pair.move_by(-300)

    with ServoPair((43, 13)) as pair:    # no invert given: zero, direction and travel come from the
        pair.go_level()                  # stored calibration (actuators/calibration.py)
        pair.go_max()                    # tilt to the recorded "max" end; go_min() for the other
        pair.move_rel(+150)              # or anywhere between: 150 ticks from LEVEL toward "max"

        pair.run_for(2.0, speed=400) # WHEEL mode: both spin for 2 s, then stop

`invert` flips a servo's direction. Two servos facing each other across a
mechanism must turn opposite ways to move it one way - that pair is
invert=(False, True).

The two modes are different things, pick by mechanism:

  move_by / move_to   The servo goes to an angle and stops there by itself.
                      Right for anything with limited travel (a tilting bed).
  run_for             The servo spins like a motor until told to stop. It has
                      NO idea where the end stops are: on limited travel it
                      drives into the frame until the time is up. Right for
                      rollers, belts, wheels.

run_for always stops both servos and puts them back in position mode, even if
the program is interrupted or the bus throws. Every command that starts motion
goes out as one sync-write packet, so the pair starts in the same instant.

CLI (from sorter/):
    python -m actuators.servo_pair move 43 13 --ticks 200 --invert-second
    python -m actuators.servo_pair run  43 13 --seconds 2 --speed 300 --invert-second
    python -m actuators.servo_pair goto 43 13 --to max        # level | min | max, from the calibration
"""
from __future__ import annotations

import logging
import sys
import time
from pathlib import Path

sys.path.insert(0, str(Path(__file__).resolve().parent.parent))

import config
from actuators.calibration import Calibration
from actuators.sts_bus import (
    ADDR_MODE,
    ADDR_TORQUE_LIMIT,
    MODE_POSITION,
    MODE_WHEEL,
    POSITION_MAX,
    StsBus,
    StsBusError,
)

log = logging.getLogger(__name__)

# Module-level so the tests can fast-forward this class's clock without touching the bus layer's.
_monotonic = time.monotonic
_sleep = time.sleep

ARRIVED_TICKS = 8
MAX_WHEEL_SPEED = 3400  # steps/s, about the servo's no-load ceiling


class ServoPair:
    def __init__(
        self,
        ids: tuple[int, int],
        invert: tuple[bool, bool] | None = None,
        torque_limit: int | None = None,
        bus: StsBus | None = None,
        mock: bool | None = None,
        calibration: Calibration | None = None,
    ) -> None:
        """ids: (leader, follower). torque_limit: 0-1000, applied to both; default config.SERVO_TORQUE_LIMIT.
        invert: leave as None to take each servo's direction from the stored calibration
        (no calibration = neither inverted). calibration: defaults to the global file."""
        if ids[0] == ids[1]:
            raise ValueError("the two servo IDs must be different")
        self.ids = tuple(ids)
        self.calibration = Calibration.load() if calibration is None else calibration
        if invert is None:
            invert = tuple(self.calibration[sid].invert if sid in self.calibration else False for sid in self.ids)
        self._sign = {ids[0]: -1 if invert[0] else 1, ids[1]: -1 if invert[1] else 1}
        self.mock = config.MOCK_HARDWARE if mock is None else mock
        self._owns_bus = bus is None
        self._bus = bus

        if self.mock:
            log.info("ServoPair %s running in MOCK mode", self.ids)
            return

        if self._bus is None:
            self._bus = StsBus(config.SERVO_PORT, config.SERVO_BAUDRATE)
        missing = [sid for sid in self.ids if not self._bus.ping(sid)]
        if missing:
            if self._owns_bus:
                self._bus.close()
            raise RuntimeError(f"servo ID(s) {missing} did not answer on {config.SERVO_PORT}")
        torque_limit = config.SERVO_TORQUE_LIMIT if torque_limit is None else torque_limit
        for sid in self.ids:
            self._bus.write_word(sid, ADDR_TORQUE_LIMIT, torque_limit)
        self._enter_position_mode()

    # --- position mode -----------------------------------------------------------
    def positions(self) -> tuple[int, int]:
        if self.mock:
            return (config.SERVO_HOME_POSITION, config.SERVO_HOME_POSITION)
        return tuple(self._bus.feedback(sid)["position"] for sid in self.ids)

    def move_to(self, targets: tuple[int, int], speed: int | None = None, acc: int | None = None,
                wait: bool = True, timeout_s: float = 6.0) -> bool:
        """Absolute positions (leader, follower), 0-4095. Returns True if both arrived
        (always True with wait=False). The servos hold the position afterwards."""
        speed = config.SERVO_MOVE_SPEED if speed is None else speed
        acc = config.SERVO_MOVE_ACC if acc is None else acc
        for target in targets:
            if not 0 <= target <= POSITION_MAX:
                raise ValueError(f"target {target} is outside 0-{POSITION_MAX}")
        if self.mock:
            log.info("[MOCK] pair %s -> positions %s", self.ids, tuple(targets))
            return True

        self._bus.sync_write_pos_ex([(sid, target, speed, acc) for sid, target in zip(self.ids, targets)])
        if not wait:
            return True
        deadline = _monotonic() + timeout_s
        while _monotonic() < deadline:
            states = [self._bus.feedback(sid) for sid in self.ids]
            if all(abs(fb["position"] - t) <= ARRIVED_TICKS and not fb["moving"] for fb, t in zip(states, targets)):
                return True
            _sleep(0.03)
        log.warning("pair %s did not reach %s within %.1f s (at %s)", self.ids, tuple(targets), timeout_s, self.positions())
        return False

    def move_by(self, ticks: int, **kwargs) -> bool:
        """Relative move: the mechanism goes `ticks` one way; an inverted servo turns the other way."""
        now = self.positions()
        return self.move_to(tuple(pos + self._sign[sid] * ticks for sid, pos in zip(self.ids, now)), **kwargs)

    # --- calibrated (mechanism) coordinates -----------------------------------------
    def move_rel(self, rel: int, **kwargs) -> bool:
        """Go to `rel` ticks from LEVEL (positive = toward the end recorded as "max"). Each
        servo's zero, direction and measured travel come from the stored calibration, so this
        means the same thing whatever angle the horns were bolted on at."""
        return self.move_to(tuple(self.calibration[sid].to_abs(rel) for sid in self.ids), **kwargs)
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

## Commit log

2026-09-19 Scaffold sorter project config and dependencies
    Central config.py holds pins, calibration placeholders, thresholds,
    servo IDs, and the MOCK_HARDWARE flag loaded via python-dotenv, so
    every later hardware-touching module has one place to read wiring
    constants from.
2026-09-19 Add mock-aware load cell and metal sensor modules
    Real mode bit-bangs the HX711 protocol on GPIO and reads the
    inductive proximity sensor with debounce; mock mode returns
    synthetic readings so both are runnable standalone (python -m
    sensors.load_cell / sensors.metal_sensor) with no hardware attached.
2026-09-19 Add camera capture and Gemini material classifier
    camera.py wraps cv2.VideoCapture for JPEG frame capture (works
    identically with a Pi camera or a laptop webcam). classifier.py wraps
    the current google-genai SDK, requests strict JSON from Gemini,
    validates it defensively, and fails toward "likely_contains_battery"
    on any timeout/error/malformed response rather than toward "safe".
    Mock mode returns a bundled placeholder JPEG / canned classification
    with no network or camera access.
2026-09-19 Add STS3215 servo controller wrapper
    Wraps the Feetech/Waveshare STServo SDK to drive the two bin-gate
    servos by ID. Mock mode logs the intended move instead of opening
    the serial port, so it's safe to exercise with nothing plugged into
    /dev/ttyACM0.
2026-09-19 Add decision fusion logic and unit tests
    fuse() is a pure function (no I/O) combining metal-sensor and Gemini
    signals into a safe/flagged verdict: flag on metal OR
    likely_contains_battery, weight reserved for future tuning. Covered
    by tests/test_decision.py, runnable via pytest or standalone.
2026-09-19 Add state machine main loop
    Explicit enum.Enum state machine: IDLE -> MEASURING -> CLASSIFYING ->
    DECIDING -> ACTUATING -> RESETTING -> IDLE. Every transition and
    sensor/decision value is logged to stdout and a rotating log file.
    The loop body is wrapped in try/except so a single bad frame or
    dropped API call logs the error and forces RESETTING instead of
    crashing or hanging. In MOCK_HARDWARE=1 mode, runs one deterministic
    end-to-end cycle for demoing without hardware; otherwise loops
    forever.
    [main.py]
2026-09-19 Add README with setup and hardware bring-up instructions
    Covers install, .env/GEMINI_API_KEY setup, running the full pipeline
    with MOCK_HARDWARE=1 on a laptop, and the incremental bring-up order
    for real hardware (power rails, camera+Gemini, load cell calibration,
    metal sensor, servos one at a time, decision logic dry run, then the
    full loop on a real item).
2026-09-19 Add STS servo bus layer over the Pi UART
    Speaks the Feetech STS protocol directly on a half-duplex one-wire bus
    (GPIO14 TX / GPIO15 RX tied through a resistor), replacing the USB bus
    adapter board and the vendor SDK. Discards its own echo and uses it as a
    wiring self-test: BusWiringError / BusContentionError / ServoTimeout say
    which side is broken. Includes a bring-up CLI (loopback, scan, watch,
    move) and unit tests against a fake wire + fake servo.
    Claude-Session: https://claude.ai/code/session_01CVqYMiqx457QE5fHkuJjFj
    [sts_bus.py, test_sts_bus.py]
2026-09-19 Drive servos through sts_bus instead of the vendor SDK
    servo_controller imported STservo_sdk, which feetech-servo-sdk does not
    provide. Use StsBus: ping configured IDs on start, enable torque, move
    with speed + acceleration, home and release torque on close. Public API
    and mock mode unchanged. Servo port defaults to the Pi 5 header UART;
    IDs are env-overridable and may be equal for the single-servo build.
    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
2026-09-19 Document direct-UART servo wiring and bring-up
    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
2026-09-19 Add nudge tool for a first, gentle servo move
    python -m tools.nudge <id>: reads the servo's state, asks before moving,
    then does one slow +100 tick move at a 30% torque limit and returns.
    Refuses when the servo's stored EEPROM angle limits would clamp the goal
    into a large swing (servos taken off another robot keep its joint
    limits); --open-limits resets them to 0-4095 first. StsBus gains
    angle_limits()/set_angle_limits() (skips the EEPROM write when unchanged).
    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
    [sts_bus.py, test_nudge.py, test_sts_bus.py]
2026-09-19 Add move_pair hardware test for the leader/follower servo pair
    python -m tests.move_pair moves servos 43 and 13 the same relative amount
    in one sync-write packet (so they start together), then returns them.
    --invert-13 mirrors the follower for servos that face each other across
    the mechanism. Slow, 30% torque limit, asks before moving, refuses if
    either servo's stored limits would clamp the goal. Named so pytest never
    collects it; test_move_pair.py covers the logic with two simulated servos.
    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
    [move_pair.py, test_move_pair.py]
2026-09-19 RPI UART Adapter + servo motor pair running
2026-09-20 Fix wheel-mode speed commands writing a goal position of 0
    write_speed/sync_write_speed sent the 7-byte block at register 41, which
    also overwrites the goal position with 0. ServoPair.close() calls stop()
    on servos that are already back in position mode, where that block means
    "go to position 0 at full speed" (torque was cut a few ms later, so on
    hardware it showed up as a twitch). Speed commands now write only the
    acceleration (41) and goal speed (46) registers; the speeds still go out
    in one sync packet. Adds a regression test.
    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
    [sts_bus.py, test_servo_pair.py]
2026-09-20 Add run_pair physical test: spin both servos for a set time
    python run_pair.py (from tests/) runs servos 43 and 13 in wheel mode via
    ServoPair.run_for: forward, pause, back. --invert-13 mirrors the
    follower. Live readout of position/load/volts/amps, then distance turned
    (counted across the 4095->0 wrap), peak load, lowest supply voltage and an
    OK/WARN/FAIL verdict. Slow, 30% torque, asks first, refuses runs over
    10 s, always leaves the servos stopped in position mode. run_for gains an
    optional on_poll callback for the readout. Not collected by pytest;
    test_run_pair.py covers it with simulated spinning servos.
    Claude-Session: https://c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
    [run_pair.py, servo_pair.py, test_run_pair.py]
2026-09-20 Add servo calibration, named setpoints and safety margins
    actuators/calibration.py stores each servo's level (zero) position, its
    recorded min/max ends and whether it is mirrored, in one JSON file that
    everything loads. Mirroring is detected from the measurements, so facing
    servos need no invert flag.
    - tests/read_positions.py (physical): torque off, move the bed by hand;
    zero / min / max / save. Shows absolute and relative-to-level ticks,
    tracks the travel seen, refuses to save travel that crosses 4095<->0.
    - ServoPair: go_level / go_min / go_max / go_to(name), move_rel(ticks from
    level), positions_rel(); direction comes from the calibration unless
    invert is passed. Both servos sti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
    [calibration.py, config.py, goto_setpoints.py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]
2026-09-20 Add the rig's measured servo calibration
    Measured 2026-09-19 with tests/read_positions.py on servos 43 and 13:
    level 2144 / 3305, recorded ends [1842, 2430] / [3016, 3607], servo 43
    mirrored. About +/-26 deg of recorded travel; the hard stops are a
    further 80-100 ticks out.
    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
    [servo_calibration.json]
2026-09-20 Require lgpio so gpiozero works on the Pi 5
    RPi.GPIO does not support the Pi 5; without lgpio gpiozero has no working
    pin factory there. Verified on the rig: DigitalInputDevice(17, pull_up=True)
    reads through LGPIOFactory.
    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
2026-09-20 Read the metal sensor on GPIO17 with the internal pull-up
    The NPN sensor's output only pulls to GND, and there is no external
    resistor on the rig: use the Pi's internal pull-up and let gpiozero handle
    active-low instead of comparing the raw value by hand. Pin moves 27 -> 17
    (env-overridable); METAL_SENSOR_PULL_UP=False keeps the external-resistor
    wiring working. Adds close() and tests against gpiozero's mock pins.
    Verified on the rig: idle reads False, line level 1.
    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
2026-09-20 Add sensor_tilt_loop physical test: metal sensor drives the bed
    python sensor_tilt_loop.py (from tests/): hold level, wait for Enter (item
    placed), wait until GPIO17 gives one consistent reading for a whole window
    (default 1 s at 20 ms; any flicker restarts it), then go_max() on metal or
    go_min() on no metal, hold, return to level, repeat. q or Ctrl+C levels
    the bed and releases torque; stops if a tilt misses its setpoint.
    Each cycle is gated on Enter because there is no weight sensor yet and the
    metal sensor cannot tell an empty bed from a plastic item (both read 1);
    --auto runs cycles back to back instead. --swap, --cycles, --window,
    --hold-s, --pause, --speed, --margin, --torque to tune.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
    [metal_sensor.py, sensor_tilt_loop.py, test_sensor_tilt_loop.py]
2026-09-20 material changed to plastic or non plastic
2026-09-20 Add plastic and battery servo logic
2026-09-20 Add HX711 driver and calibrated load cell
    - sensors/hx711.py: standalone HX711 driver (gain select, median reads)
    - sensors/load_cell.py: read through the driver; tare(), calibrate(), save();
    calibration loaded from load_cell_calibration.json, falling back to config
    - load_cell_calibration.json: measured on the rig 2026-09-20
    (10 kg bar cell, gain 128: zero -194131, 209.096 counts/g)
    - config.py: HX711_GAIN, calibration file path, measured fallback values
    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
2026-09-20 Start main.py on a weight RISE of more than 10 g, not an absolute weight
    WAITING now measures the bed's resting weight and triggers when a reading
    rises more than WEIGHT_DELTA_TRIGGER_G (10 g, env-overridable) above it, so
    the scale's zero no longer has to be right. The resting level follows slow
    drift (readings within 3 g are blended in), adopts a lighter level when
    something is taken off, and is re-measured after every dump. The logged
    item weight is what the item added. Mock mode still fires every loop.
    main_enter.py is unaffected (it never touches the load cell). Adds
    tests/test_main.py with a scripted scale.
    Claude-Session: https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
    [config.py, main.py, test_main.py]
2026-09-20 Cut the time between returning to level and accepting the next item
    Per cycle the reset spent ~4 s: a fixed 1.5 s pause, a 15-sample re-tare
    (~1.3 s), a 5-sample resting read and a 0.1 s poll sleep. The re-tare is
    redundant now that the trigger is a rise above a freshly measured resting
    weight, so it is gone (tare only at start-up). The resting weight is taken
    as soon as three consecutive readings agree to within 3 g - ~0.3 s on a
    still bed, a few readings longer on one that is still bouncing - instead of
    waiting a fixed time. RESETTING_PAUSE_S 1.5 -> 0.2 (env-overridable), poll
    sleep removed (each HX711 read already blocks ~85 ms), polls use 2 samples.
    Reset-to-ready is now about 1 s.
    Co-A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
    [config.py, main.py, test_main.py]
2026-09-20 Add project README
    Project-level README at the repo root, based on the Devpost write-up:
    the problem, what SortiFy does, architecture and state-machine diagrams,
    the decision rule and why the sensor (not the model) has the final say,
    hardware and Pi wiring, the engineering story behind the direct-UART
    servo bus / echo check / calibration / HX711 timing guard / delta weight
    trigger, how to run it, the bring-up tools, what we learned, what's next
    and the team. Setup detail stays in sorter/README.md.
    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
